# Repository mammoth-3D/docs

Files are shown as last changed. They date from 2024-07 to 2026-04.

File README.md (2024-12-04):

# mammoth-3D Documentation

The **Mammoth-3D Documentation** serves as an essential resource for several key reasons:

### 1. **Comprehensive Learning Resource**
The documentation offers a thorough overview of all the features and functionalities of the Mammoth-3D platform. Whether you're a beginner learning the basics or an advanced user exploring complex capabilities, the documentation provides step-by-step guides, tutorials, and detailed explanations. It helps users understand the various tools and how to apply them effectively in their projects.

### 2. **Efficient Problem-Solving**
Encountering issues or needing clarification on specific functionalities is common when using any complex software. The Mammoth-3D documentation acts as a troubleshooting guide, offering solutions to common problems and detailed instructions on how to navigate challenges. This can save users time and reduce frustration by providing quick answers and alternative approaches.

### 3. **Enhanced Workflow Integration**
For professionals using multiple software applications, understanding how Mammoth-3D integrates with other tools is crucial. The documentation covers compatibility, import/export processes, and best practices for maintaining data integrity across platforms. This information helps users create a seamless workflow, ensuring that their work in Mammoth-3D can be efficiently incorporated into broader projects.

### 4. **Access to Advanced Features**
Mammoth-3D offers a wide range of advanced features, including scripting and real-time collaboration. The documentation details how to access and utilize these features, enabling users to fully exploit the platform's potential. For instance, developers can learn how to write scripts to automate tasks, while teams can discover how to collaborate effectively on shared projects.

### 5. **Up-to-Date Information**
As Mammoth-3D continues to evolve, the documentation is regularly updated to reflect the latest features, updates, and best practices. This ensures that users have access to the most current information, helping them stay up-to-date with the latest developments and improvements in the software.

### 6. **Community and Support**
The documentation often includes links to community forums, support channels, and additional learning resources. This connectivity provides users with opportunities to ask questions, share experiences, and learn from other community members. It's an invaluable aspect of the documentation that extends learning beyond the written material.

In summary, the Mammoth-3D Documentation is an invaluable tool for maximizing the efficiency, effectiveness, and creativity of users on the platform. It provides essential information and support, making it an indispensable resource for anyone looking to master Mammoth-3D.

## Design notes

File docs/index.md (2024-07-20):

# **mammoth-3D Documentation**

mammoth-3D mods for 3D printers represent a significant leap forward in enhancing the capabilities of your 3D printing setup. Here's why they stand out in terms of design, functionality, performance, and user-friendliness, and how easily they integrate with popular printers like Voron, VZBOT, RatRig vCore, and many more:

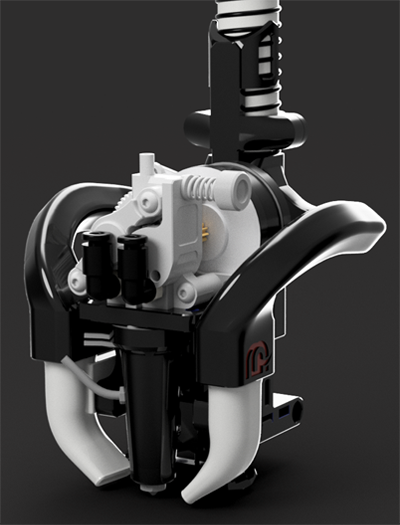
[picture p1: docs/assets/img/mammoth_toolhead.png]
mammoth-3D Toolhead


**Innovative Design**
mammoth-3D mods are meticulously crafted with a focus on both form and function:

- **Robust and Durable:** 
Built from high-quality materials, these mods are designed to last, ensuring your printer performs reliably over the long term.

- **Optimized Weight Distribution:** 
Careful design minimizes vibrations, leading to higher quality prints with fewer defects.

- **Aesthetic Appeal:** 
Sleek and modern designs not only enhance the functionality but also add a visually appealing touch to your printer.

**Unmatched Functionality**
Mammoth-3D mods are loaded with features that significantly improve the 3D printing experience:

- **Advanced Cooling Systems:** 
Ensures even temperature distribution, reducing the risk of warping and resulting in smoother, more precise prints.

- **Precision Mechanics:** 
High-precision components guarantee accurate movements, producing high-resolution prints with intricate details.

- **Customizable Settings:** 
Offers flexibility to adjust settings for specific printing needs, making it suitable for a wide range of projects.

**Superior Performance**
Experience the pinnacle of 3D printing performance with Mammoth-3D mods:

- **Enhanced Speed:** 
Optimized motion systems allow for faster printing speeds while maintaining high-quality output.

- **Consistency and Reliability:** 
Designed to deliver consistent performance over extended print runs, reducing material wastage and failed prints.

- **Energy Efficiency:** 
Engineered for power efficiency, these mods help lower operational costs and minimize environmental impact.

**User-Friendly Experience**
Mammoth-3D mods are designed with the user in mind, ensuring an easy and enjoyable printing experience:

- **Intuitive Interface:** 
Simple and user-friendly interfaces make setup and operation straightforward, even for beginners.

- **Comprehensive Documentation:**
Detailed guides and manuals help users quickly understand and implement the mods.

**Responsive Customer Support:** 
Dedicated support is available to assist with any questions or issues, ensuring a smooth user experience.

**Seamless Integration**
One of the standout features of Mammoth-3D mods is their compatibility with a wide range of 3D printers:

- **Modular Design:** These mods are designed to be modular, allowing for easy integration and upgrades across different printer models.

- **Plug-and-Play Installation:** Most mods can be installed with minimal adjustments, requiring only basic tools and technical knowledge.

- **Broad Compatibility:** Extensive testing ensures that Mammoth-3D mods work seamlessly with various firmware and hardware configurations, providing stability and optimal performance.

**Engaged Community and Ecosystem**
Join a vibrant community of 3D printing enthusiasts with Mammoth-3D:

- **Open Source and Customization:** Many mods are open source, encouraging users to customize and tweak them to fit specific needs.

- **Regular Updates:** Continuous improvements and updates based on community feedback keep the mods at the cutting edge of 3D printing technology.

**Conclusion:**

Mammoth-3D mods elevate your 3D printing experience through innovative design, superior functionality, exceptional performance, and user-friendly features. Their easy integration with a variety of 3D printer models, such as Voron, VZBOT, RatRig vCore, and more, makes them the ideal choice for anyone looking to enhance their 3D printing setup. Whether you are a hobbyist or a professional, Mammoth-3D mods provide the versatility and reliability needed to achieve outstanding printing results.

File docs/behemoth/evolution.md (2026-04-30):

# From mammoth to behemoth
## Engineering the Next Stage of High-Performance Gantries

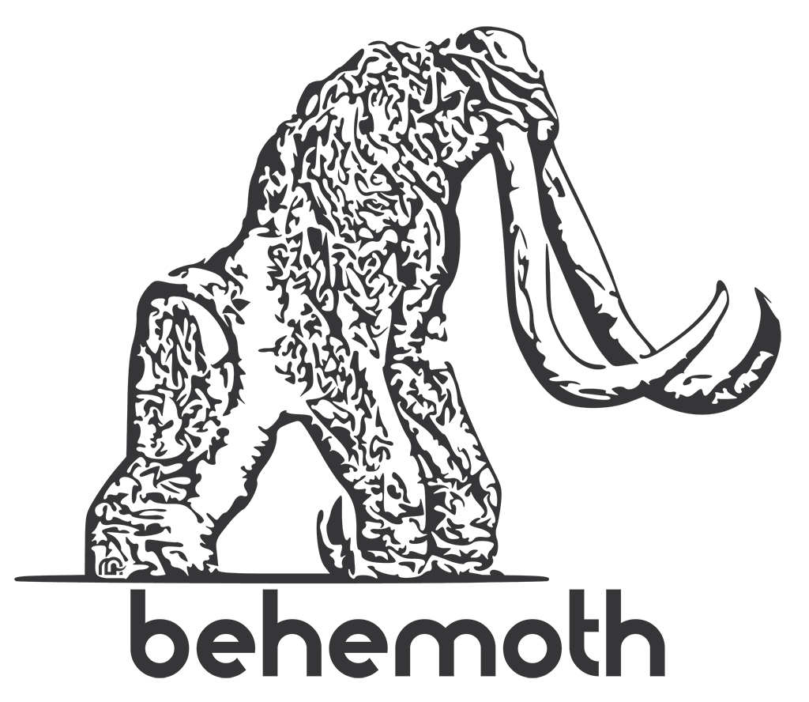
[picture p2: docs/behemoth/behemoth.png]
mammoth-3D Toolhead


In 2023, the open-source 3D printing landscape was largely defined by two platforms:

- Voron — known for precision engineering and strong community documentation  
- VZBot — known for aggressive speed and high-performance motion systems  

Each represented a different philosophy.

**mammoth** was created to unify them.

---

# Mammoth: Where Two Worlds Met

The mammoth-3D AWD Gantry was not an adapter or a light modification.

It was a complete ground-up redesign.

The goal was simple:

**Combine the structural precision of Voron with the speed-focused performance of VZBot — without compromise.**

## What mammoth Delivered

- True cross-compatibility between ecosystems  
- Support for high-speed configurations (30T pulleys)  
- Long shaft motor compatibility (5mm & 8mm)  
- Toolhead flexibility across platforms  

Rather than forcing one system into another, mammoth reimagined the gantry architecture itself.

It proved that performance and flexibility could coexist within a single engineered solution.

---

# Evolution Is Not a Version Number

behemoth is not “mammoth V2.”

It represents a structural shift in direction.

Where mammoth focused on merging ecosystems,  
behemoth focuses on establishing its own.

---

# behemoth: Designed for Independence

behemoth is engineered to move beyond adaptation.

It is the foundation of a standalone 3D printer platform — built with scalability, strength, and long-term evolution in mind.

---

## Built for Scale From the Start

- Initial platform size: **400 × 400mm**
- Long-term development target: **1000 × 1000mm multi-toolhead capability**

behemoth is not constrained by traditional desktop dimensions.

It is engineered to support large-format, high-rigidity builds from day one.

---

## Transitional Compatibility

In its current stage, behemoth supports Voron printers.

As development progresses, the platform transitions toward **3030 aluminum profile architecture**, creating a stronger and more independent structural standard.

This ensures long-term scalability and mechanical stability.

---

## Configurable Belt Architecture

behemoth supports multiple belt widths:

- 6 mm  
- 9 mm  
- 10 mm  
- 12 mm  

This allows builders to balance speed, torque capacity, and structural rigidity according to their performance goals.

---

## The mammoth Idler Pack — Refined Engineering

After a year of iterative testing and refinement, the idler system has been significantly improved:

- Direct access to idlers and bearings  
- No motor mount removal required  
- Belt tensioning through the idler pack  
- Reduced stress on motor shafts  

This design increases serviceability while improving long-term mechanical reliability.

---

## Builder-Focused Flexibility

behemoth supports:

- Double-shear configurations  
- Traditional idler setups  
- Modular customization options  

The platform is engineered to provide flexibility without sacrificing structural integrity.

---

# The Strategic Shift

mammoth demonstrated that ecosystems could be unified.

behemoth establishes a platform that can stand independently.

It reflects a move from integration  
to long-term architectural ownership.

---

# The Next Phase

behemoth is not the final form.

It is the beginning of a larger platform vision.

Further features and refinements will be introduced in the coming weeks as development continues.

If you would like to follow the progression or contribute feedback,  
join the discussion in [**#behemoth-general**](https://discord.com/channels/1240273232247132233/1470169338995675187)

**Engineering evolves. So do we.**

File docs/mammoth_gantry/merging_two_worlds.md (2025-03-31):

# **mammoth-3D AWD Gantry: Merging Two Worlds**

## **Origins of the mammoth-3D AWD Gantry**  

The idea for the **mammoth-3D AWD gantry** began in **April 2023**. At the time, **Voron 3D printers** were leading the open-source printer community, while **VZBot 3D printers** were pushing the boundaries of high-speed printing with impressive quality. 
This sparked a race, who would be the first to adapt and run a **VZBot toolhead** on a **Voron printer**?  

In **June 2023**, the **mammoth-3D Toolhead** was developed, allowing users to equip their **Voron printers** with the **Goliath hotend** and **CPAP cooling** for improved performance.  

By the end of **2024**, the **mammoth-3D AWD Gantry v6** was finalized—the first version made publicly available, documented as **version 1.7.3**.  

---

## **What Makes the mammoth-3D AWD Gantry Unique?**

Unlike modifications that adapt a **Voron gantry** to fit a **VZBot toolhead**, we **designed an entirely new gantry** from the ground up.  

### **Key Features**  

- **Cross-Compatible** – Use either **Voron toolheads** or the **VZBot toolhead** on the new gantry.  
- **Expanded Printer Support** – Now, **Voron toolheads** can also be mounted on a **VZBot printer**.  
- **High-Speed Optimization** – Supports **30T pulleys** and **long shaft motors (5mm or 8mm)**, allowing for maximum speed and flexibility in component selection.  

By doing this, we’ve effectively **brought two worlds together**, offering the best of both **Voron** and **VZBot** ecosystems.  

---

## ⚠️ **Important Considerations Before Installing**  

Before you decide to build a **mammoth-3D AWD gantry**, please be aware of the following:  

### 🔹 **No Official Voron Manual**  
While we provide **documentation** and a **Discord group**, our guide is not as detailed as the **Voron** manual. You should already be **comfortable assembling a stock 3D printer** before attempting this build.  

### 🔹 **Most Existing Parts Won’t Fit**  
Your current **gantry parts** will likely be **incompatible** with the new design, meaning you’ll need to **invest in new components**.  

### 🔹 **Frame Modifications Required**  
The **aluminum profiles** have changed and will need to be **cut to fit** your new gantry. Detailed information is available in the **[source guide](https://docs.mammoth-3d.ch/voron_3d_printers/awd_gantry_vz_toolhead_printed_version/bom/awdvz_sourcing_guide/)**.  

---

## **Welcome to the mammoth-3D Family!**  

If you’ve read through all of this and still want to take on the challenge, **welcome to the mammoth-3D family**. Where we push the limits of **high-speed, high-quality** 3D printing. 🚀

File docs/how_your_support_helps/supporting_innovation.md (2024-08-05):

## **Supporting Innovation with mammoth-3D. Find us on [Printables.com](https://www.printables.com/@Mammoth3D_2076590/models)**

By choosing to pay a small fee ($5 - $10) for Mammoth-3D parts, end users contribute to the continuous development and innovation of Mammoth-3D’s 3D printing technology. This support enables Mammoth-3D to:

- **Develop New Parts and Enhancements**: Ongoing revenue helps fund research and development, leading to improved and more efficient 3D printing components.
- **Improve Quality and Performance**: Continuous improvement efforts ensure that Mammoth-3D parts meet the highest standards of quality and performance.
- **Expand Material Options**: Funding supports the exploration and introduction of new materials, providing users with more choices for their projects.

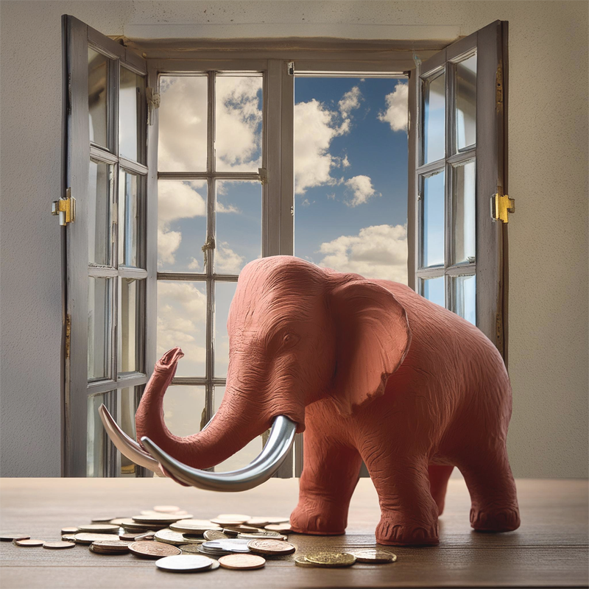
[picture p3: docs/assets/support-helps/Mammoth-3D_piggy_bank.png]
Mammoth-3D on www.printables.com


Mammoth-3D on www.printables.com mammoth-3D Piggy Bank (https://www.printables.com/@Mammoth3D_2076590/models)

**Open Source:**

Additionally, Mammoth-3D ensures that its contributions to the 3D printing community extend beyond immediate financial support. All published files and projects will move to open source after a period of six months. This means that if an end user does not wish to pay for the project files now, they will have access to these resources for free after six months. This approach balances immediate funding needs with a long-term commitment to open access and community support.

**The Cost of Development and Engineering Work for 3D Printed Components**

3D printing, also known as additive manufacturing, has revolutionized the manufacturing industry by offering unprecedented flexibility, customization, and efficiency. However, developing a 3D printed component or part involves various stages and costs. This blog will delve into the cost factors associated with the development and engineering work required to create a 3D printed part.

**1. Initial Design and Conceptualization**

The first stage in developing a 3D printed component is the design and conceptualization phase. This involves translating an idea into a viable digital model using Computer-Aided Design (CAD) software. The costs here are influenced by:

**Design Software**

- **CAD Software Licenses**: Professional CAD software can range from $100 to $1,000 per year per license. For complex projects, advanced software like SolidWorks, AutoCAD, or Rhino might be required.
- **Specialized Plugins and Tools**: Depending on the project's complexity, additional plugins or tools may be needed, further increasing the software costs.

**Designer and Engineer Fees**

- **Hourly Rates**: The hourly rate for a skilled designer or engineer can vary widely, from $50 to $150 or more, depending on their expertise and location.
- **Project Complexity**: More complex designs require more time and expertise, driving up costs.

**2. Prototyping and Testing**

Once the initial design is ready, prototyping and testing come into play. This phase ensures the design is functional and meets the required specifications.

**3D Printing Costs**

- **Material Costs**: The type of material used for 3D printing significantly impacts the cost. Common materials like PLA or ABS are cheaper, while specialized materials like metal or resin can be much more expensive. Prices range from $20 per kilogram for basic plastics to over $500 per kilogram for high-performance materials.
- **Printer Costs**: The cost of using a 3D printer depends on whether you own the printer or need to use a service. Owning a professional-grade 3D printer can cost anywhere from $5,000 to $100,000 or more. Alternatively, outsourcing to a 3D printing service can cost anywhere from $10 to $100 per printed part, depending on the size and complexity.

**Iterations and Refinements**

- **Multiple Prototypes**: Developing a final product often requires multiple iterations. Each prototype involves additional printing costs and time, with each iteration potentially costing between $50 and $500 or more, depending on the complexity and material used.
- **Testing and Analysis**: Testing the prototypes for functionality, durability, and compliance with specifications can involve additional costs, including specialized equipment and labor.

**3. Final Production Preparation**

Once the design is finalized, preparing for production involves several additional steps and costs.

**Final Design Adjustments**

- **Optimization for Manufacturing**: Adjusting the design to optimize it for mass production, such as reducing material usage or simplifying assembly, can require additional design work and cost.
- **Detailed Documentation**: Creating detailed manufacturing instructions, assembly guides, and quality assurance documents is essential for smooth production.

**Quality Assurance and Certification**

- **QA Processes**: Implementing quality assurance processes to ensure each part meets the required standards can add to the cost. This may involve additional testing, inspection, and documentation.
- **Certification Costs**: Depending on the industry, certification (e.g., ISO, CE) might be required, which involves additional costs for compliance testing and documentation.

**4. Post-Production Considerations**

Post-production costs can also impact the overall budget for developing a 3D printed part.

**Post-Processing**

- **Finishing and Assembly**: Post-processing steps like sanding, painting, or assembling multiple parts can add to the cost. These processes can be labor-intensive and may require specialized equipment.
- **Surface Treatment**: Additional treatments, such as heat treatment for metal parts or UV curing for resin parts, can further increase costs.

**Distribution and Logistics**

- **Packaging**: Proper packaging to protect the parts during transportation is necessary and can add to the cost.
- **Shipping**: Depending on the size and weight of the parts, shipping costs can vary significantly, especially for international shipments.

**Conclusion**

The cost of developing and engineering a 3D printed component or part is influenced by various factors, including design and conceptualization, prototyping and testing, final production preparation, and post-production considerations. While 3D printing offers significant advantages in terms of flexibility and customization, careful consideration of the associated costs is crucial for a successful and economically viable project. Additionally, by paying a small fee for Mammoth-3D parts, users not only receive high-quality components but also support the ongoing innovation and development efforts of Mammoth-3D, ensuring continuous improvements and advancements in 3D printing technology. Plus, the promise of open-source access after six months makes it an inclusive initiative that benefits the entire 3D printing community.

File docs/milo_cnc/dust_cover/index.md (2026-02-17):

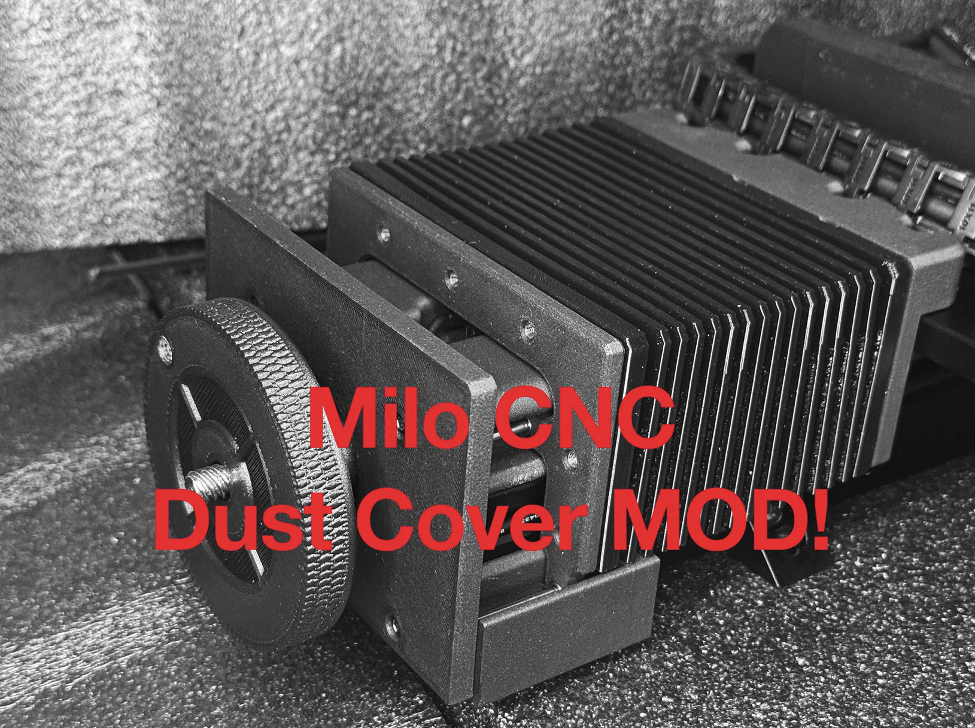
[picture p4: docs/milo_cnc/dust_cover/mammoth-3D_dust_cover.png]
mammoth-3D Milo CNC Dust Cover
# **The Milo CNC Dust Cover by mammoth-3D** 

**Why This Mod Helps.**

- By shielding your rails and lead screw, this dust cover reduces contamination, lowers maintenance, and keeps your machine running smoother for longer. Perfect for woodworking, plastics, aluminum, and general CNC use.

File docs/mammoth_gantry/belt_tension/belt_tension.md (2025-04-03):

# **Belt Tension Calculator**

## ⚠️ **Important: Check Before Tensioning!**  

Before you start tensioning your belts, **ensure the tensioner is not pulling on the motor shaft!**  

### 🛠️ **Examples of setups where this applies:**
- All AWD upgrades for Voron printers with the default belt configuration  
- Monolight gantry  
- VZBot 235 and 330  

### 🚨 **Avoid Motor Shaft Damage!**  
Applying too much tension at once **can cause the motor shaft to bend or even result in permanent damage**.  

### 🚨 **Double Shear Bearing** 

If your gantry uses **double shear** bearings to support the motor shaft, you don’t need to worry about bending the shaft. However, if you're tensioning the belts via the motor shaft, be cautious not to **overstretch the belt**.

### ✅ **Recommended Tensioning Steps:**  
1. Start with an initial tension of **110-120 Hz**.  
2. **Increase in steps of 10–15 Hz at a time**.  
3. Move the gantry and belts to distribute tension.  
4. Repeat the process **only if needed** to reach the desired tension.    

Following this method ensures **a safer and more precise tensioning process**.  

## **Registration Drives**
Registration drives are crucial for accurate positioning, especially in applications like 3D printers. Higher belt tensions can improve belt tensile modulus and increase meshing interference, both of which help reduce backlash. The optimal tension values for these applications should be determined experimentally to ensure the desired performance characteristics are met.

As a starting point, a registration factor between **1.5** and **2.0** is recommended. However, it’s important to note that many 3D printers may not be able to handle a registration drive factor over **1.0**. You can find more infos in the **[Gates PDF](https://www.gates.com/content/dam/gates/home/knowledge-center/resource-library/catalogs/light-power-and-precision-manual.pdf)**.

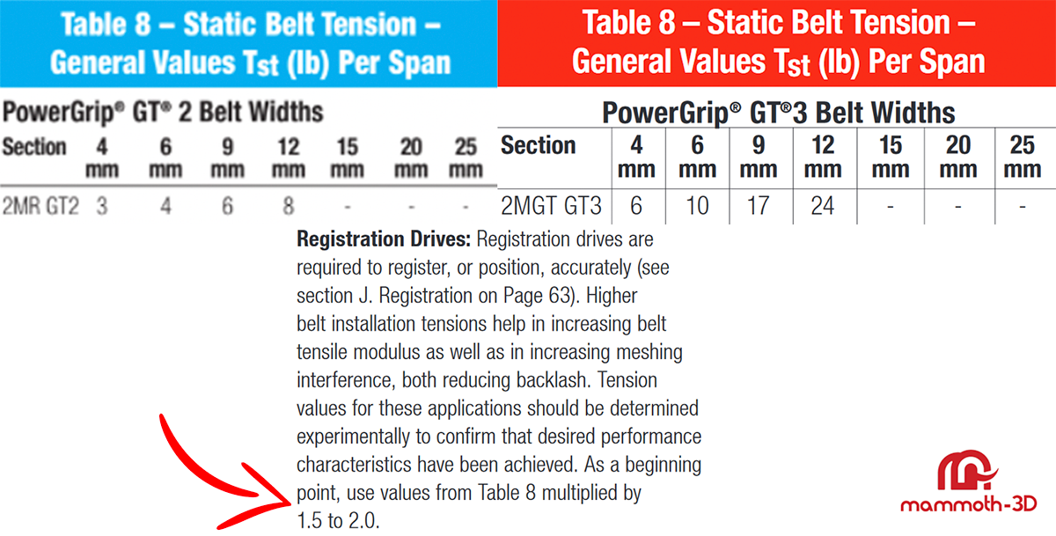
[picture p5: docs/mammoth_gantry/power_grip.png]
Power Grip

### **For example:** 
**Voron [(Belt Tension)](https://docs.vorondesign.com/tuning/secondary_printer_tuning.html#belt-tension)** printers specify a registration factor of **0.5** on GT2 6mm belts (equivalent to **2lb** of tension) and **VZbot [(Belt Tension)](https://docs.vzbot.org/general/belt-tensioning/#vzbot-330)** printers specify a registration factor of **0.8375** up to **1.5** on GT2 6mm belts (equivalent to **3.35lb** up to **6lb** of tension)

## **Calculator**
Use this calculator to determine the optimal belt tension frequency, or refer to the table below for quick belt information.

<style>
    :root {
        --md-primary-fg-color:        #9E1414;  /* Primary Red */
        --md-accent-fg-color:         #EC6565;  /* Accent Red */
        --md-primary-fg-color--light: #AD4343;  /* Light Red */
        --md-primary-fg-color--dark:  #9E1414;  /* Dark Red */
    }

    .calculator-table {
        width: 100%;
        max-width: 600px;
        margin: auto;
        border-collapse: collapse;
    }

    .calculator-table th, .calculator-table td {
        border: 1px solid var(--md-primary-fg-color--light);
        padding: 10px;
        text-align: left;
    }

    .calculator-table th {
        background-color: var(--md-primary-fg-color--light);
        color: white;
    }

    select, input {
        width: 100%;
        padding: 8px;
        font-size: 16px;
        border: 1px solid var(--md-primary-fg-color--light);
    }

    button {
        width: 100%;
        padding: 10px;
        background-color: var(--md-primary-fg-color); /* Primary Red */
        color: white;
        font-size: 18px;
        border: none;
        cursor: pointer;
    }

    button:hover {
        background-color: var(--md-primary-fg-color--dark); /* Dark Red */
    }

    #result {
        font-size: 18px;
        font-weight: bold;
        text-align: center;
        margin-top: 15px;
        color: var(--md-primary-fg-color);
    }

    .shadow {
        height: auto;
        width: auto;
        box-shadow: 0 0 5px 5px white;
    }

    .mermaid {
        display: flex !important;
        justify-content: center;
    }

    .shadow-dark {
        height: auto;
        width: auto;
        box-shadow: 0 0 5px 5px #1e1e1e;
    }

    .md-typeset__table {
        min-width: 100%;
    }

    .md-typeset table:not([class]) {
        display: table;
    }
</style>

<table class="calculator-table">
    <tr>
        <th>Select Belt Type:</th>
        <td>
            <select id="beltType">
                <option value="GT2">GT2</option>
                <option value="GT3">GT3</option>
            </select>
        </td>
    </tr>
    <tr>
        <th>Select Belt Width (mm):</th>
        <td>
            <select id="beltWidth">
                <option value="6">6 mm</option>
                <option value="9">9 mm</option>
                <option value="10">10 mm</option>
                <option value="12">12 mm</option>
            </select>
        </td>
    </tr>
    <tr>
        <th>Select Factor:</th>
        <td>
            <select id="factor">
                <option value="1">1</option>
                <option value="1.25">1.25</option>
                <option value="1.5">1.5</option>
                <option value="1.75" selected>1.75 (Default)</option>
                <option value="2">2</option>
            </select>
        </td>
    </tr>
    <tr>
        <th>Enter Belt Length (mm):</th>
        <td>
            <input type="number" id="beltLength" value="150">
        </td>
    </tr>
    <tr>
        <td colspan="2">
            <button id="calculate">Calculate</button>
        </td>
    </tr>
</table>

## **mammoth-3D Gantry Belt Tension** 

All mammoth-3D gantries are designed with the same principle: **Do not pull on the motor shaft when tensioning the belts**.  

Whether it's a Voron or VZBot gantry, they all function the same way. Over-tensioning can still damage short motor shafts, even if they are not directly used for belt tensioning.  

Refer to the table below for the recommended belt tension values for mammoth-3D gantries.

### **Belt Tension / Short Shaft Motor**  

| **mammoth-3D Gantry** | **GT2 Belts Minimum Tension** | **GT2 Belts Maximum Tension** | **GT3 Belts Minimum Tension** | **GT3 Belts Maximum Tension** |  
|:---|:---:|:---:|:---:|:---:|
| **3D Printed** | 6mm Belts 147.40Hz / 4lbf | 6mm Belts 180.53Hz / 6lbf | ❌ Not Recommended | ❌ Not Recommended |  
| **Aluminum** | 6mm Belts 147.40Hz / 4lbf | 6mm Belts 180.53Hz / 6lbf | ❌ Not Recommended | ❌ Not Recommended |  

### **Belt Tension / Long Shaft Motor (Double Shear)**  

| **mammoth-3D Gantry** | **GT2 Belts Minimum Tension** | **GT2 Belts Maximum Tension** | **GT3 Belts Minimum Tension** | **GT3 Belts Maximum Tension** |  
|:---|:---:|:---:|:---:|:---:|
| **3D Printed** | 6mm Belts 180.53Hz / 6lbf | 6mm Belts 194.99Hz / 7lbf | ❌ Not Recommended | ❌ Not Recommended |  
| **Aluminum** | 6mm Belts 180.53Hz / 6lbf | 6mm Belts 194.99Hz / 7lbf | 6mm Belts 258.45.53Hz / 15lbf| 6mm Belts 279.16Hz / 17.5lbf |

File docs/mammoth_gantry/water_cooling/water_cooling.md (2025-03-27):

# **Water Cooling**

!!! tip
    **The water cooling inlet should always (or if possible) be the lowest point and the outlet should always be the highest point in your water cooling setup.**

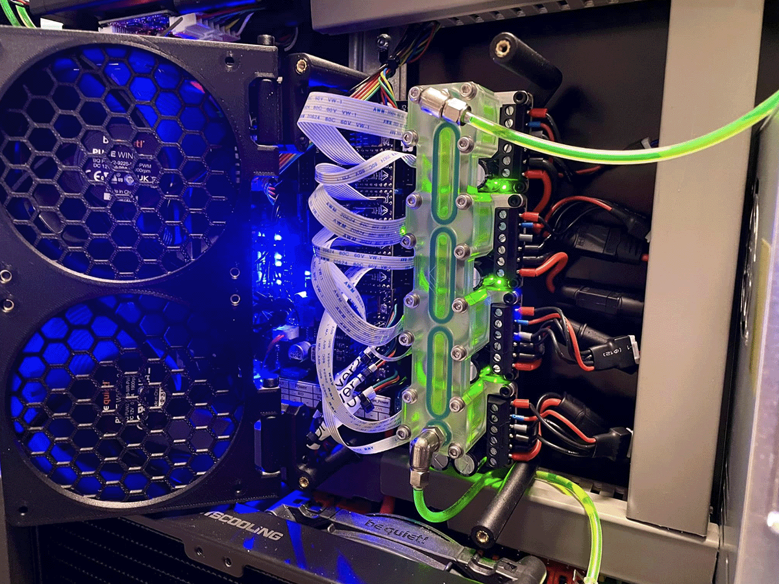
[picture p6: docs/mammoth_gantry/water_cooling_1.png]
Water Cooling setup


!!! note "Pipe Length"
    The pipe length between the hotend and Y1 motor, as well as between the X and Y motors and the X1 motor and pump, is very long. It is recommended to use quick connectors for the day you need to remove the gantry without having to remove all the pipes as well.

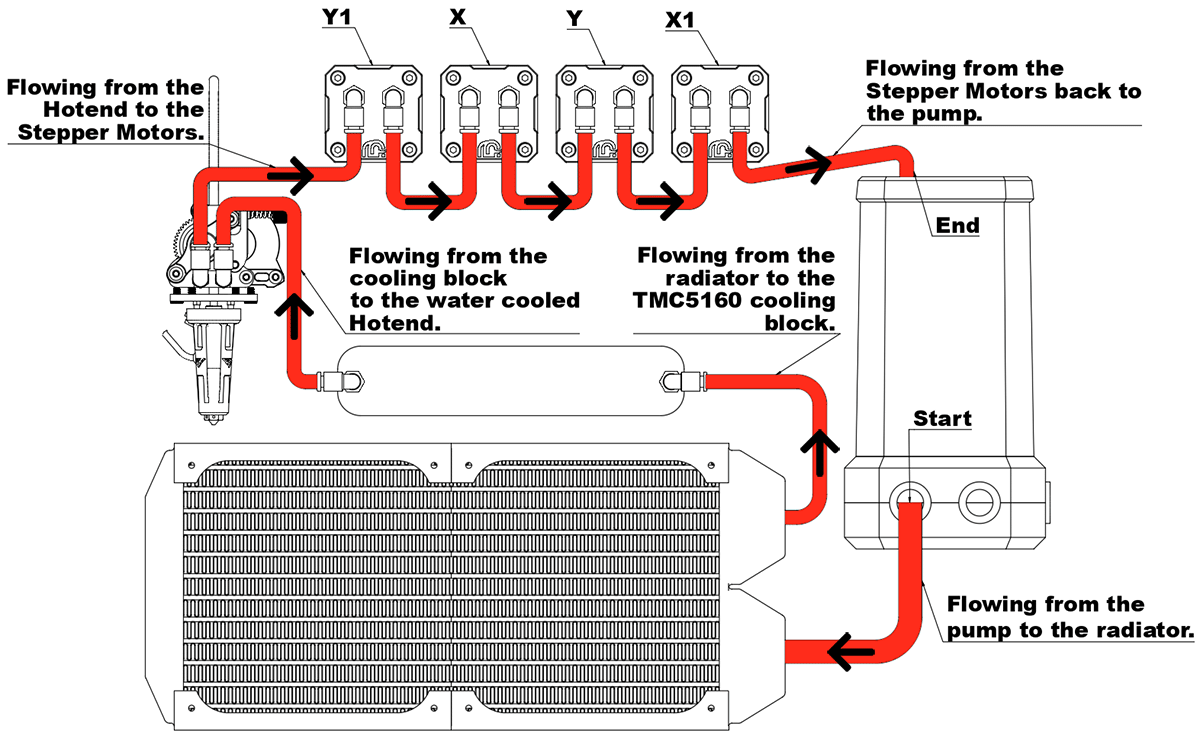
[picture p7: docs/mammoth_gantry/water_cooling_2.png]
Pipes


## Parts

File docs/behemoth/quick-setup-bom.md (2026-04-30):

<!DOCTYPE html>
<html>
<head>
  <title>behemoth BOM Generator</title>
</head>
<body>

<h2>BOM Configuration</h2>

<label><strong>3D Printer</strong></label><br>
<select id="printer">
  <option value="">-- Select Printer --</option>
  <option>behemoth</option>
  <option>Voron 2.4</option>
  <option>Voron Trident</option>
</select><br><br>

<label><strong>Printer Size</strong></label><br>
<select id="size">
  <option value="">-- Select Size --</option>
  <option>300</option>
  <option>350</option>
  <option>400</option>
</select><br><br>

<label><strong>Hotend</strong></label><br>
<select id="hotend">
  <option value="">-- Select Hotend --</option>
  <option>Hell Fire</option>
  <option>Goliath Air</option>
  <option>Goliath Water</option>
  <option>Rapido</option>
  <option>Tricorn</option>
</select><br><br>

<label><strong>X Axis</strong></label><br>
<select id="axis"></select><br><br>

<label><strong>XY Belts</strong></label><br>
<select id="belt">
  <option value="">-- Select Belt --</option>
  <option>9mm</option>
  <option>12mm</option>
</select><br><br>

<label><strong>Motor Shaft Diameter</strong></label><br>
<select id="diameter">
  <option value="">-- Select Diameter --</option>
  <option>5mm</option>
  <option>8mm</option>
</select><br><br>

<label><strong>Motor Shaft Length</strong></label><br>
<select id="length">
  <option value="">-- Select Length --</option>
  <option>20mm to 25mm</option>
  <option>30mm to 40mm</option>
  <option>55mm to 60mm</option>
</select>

<br><br>

<button onclick="downloadCSV()">Download CSV</button>

<hr>

<table border="1" width="100%">
<thead>
<tr>
  <th>Qty</th>
  <th>Part Number</th>
  <th>Description</th>
  <th>Link</th>
</tr>
</thead>
<tbody id="bomTable">
<tr><td colspan="4">Make selections</td></tr>
</tbody>
</table>

<script>

// ---------------- DATA ----------------
let bom = {};

// ---------------- PART NUMBER ----------------
function makePartNumber(name){
  return "BH-" + name
    .toLowerCase()
    .replace(/behemoth/g, "")
    .replace(/voron/g, "")
    .replace(/v24/g, "")
    .replace(/vt/g, "")
    .replace(/[^a-z0-9]+/g, "-")
    .replace(/-+/g, "-")
    .replace(/^-|-$/g, "")
    .toUpperCase()
    .substring(0, 40);
}

// ---------------- LINK ----------------
function makeLink(partNumber){
  return `https://behemoth.local/${partNumber}`;
}

// ---------------- ADD ITEM ----------------
function addItem(qty, name){

  const key = makePartNumber(name);

  if(!bom[key]){
    bom[key] = {
      qty: 0,
      part: key,
      desc: name,
      link: makeLink(key)
    };
  }

  bom[key].qty += qty;
}

// ---------------- AXIS RULE (UPDATED) ----------------
function updateAxis(){

  const size = sizeEl.value;
  axisEl.innerHTML = `<option value="">-- Select Axis --</option>`;

  if(!size) return;

  if(size === "300"){
    axisEl.innerHTML += `<option>High Speed 300</option>`;
    axisEl.innerHTML += `<option>High Temp 300</option>`;
  }

  if(size === "350"){
    axisEl.innerHTML += `<option>High Speed 350</option>`;
    axisEl.innerHTML += `<option>High Temp 350</option>`;
  }

  if(size === "400"){
    // 🚨 ONLY HIGH TEMP ALLOWED
    axisEl.innerHTML += `<option>High Temp 400</option>`;
  }
}

// ---------------- MAIN ----------------
function generateBOM(){

  bom = {};

  const printer = printerEl.value;
  const size = sizeEl.value;
  const hotend = hotendEl.value;
  const axis = axisEl.value;
  const belt = beltEl.value;
  const diameter = diameterEl.value;
  const length = lengthEl.value;

  if(!printer || !size || !hotend || !axis || !belt || !diameter || !length){
    table.innerHTML = "<tr><td colspan='4'>⚠️ Complete selections</td></tr>";
    return;
  }

  // ---------------- SAFETY CHECK ----------------
  if(size === "400" && axis.includes("High Speed")){
    table.innerHTML = "<tr><td colspan='4'>❌ Invalid: 400 only supports High Temp axis</td></tr>";
    return;
  }

  // ---------------- BASE ----------------
  const baseSets = [
    "Set1 X1 Y1 Motor Mount",
    "Set2 X Y Motor Mount",
    "Set3 X1 Y1 Idler Pack",
    "Set4 Tension Arms",
    "Set5 X Y Idler Pack",
    "Set6 XY Joiners",
    "Set22 Toolhead"
  ];

  baseSets.forEach(s => addItem(1, s));

  if(printer === "behemoth" || printer === "Voron 2.4"){
    addItem(1, "Set12 V24 Fixed Z Joints");
  }

  if(printer === "Voron Trident"){
    addItem(1, "Set13 VT Fixed Z Joints");
  }

  // ---------------- HOTEND ----------------
  if(hotend === "Hell Fire"){
    addItem(1, "Set25 Hell Fire Plate");
    addItem(1, "Set28 Hell Fire 150W");
  } else {
    addItem(1, "Set26 Universal Hotend Plate");
  }

  // ---------------- AXIS ----------------
  addItem(1, axis + " X-Axis");

  // ---------------- BELT ----------------
  if(belt === "9mm"){
    addItem(6, "Set14 9mm Idler Teeth");
    addItem(8, "Set15 9mm Idler Smooth");
    addItem(1, "Set23 9mm Clamp");
  } else {
    addItem(6, "Set16 12mm Idler Teeth");
    addItem(8, "Set17 12mm Idler Smooth");
    addItem(1, "Set24 12mm Clamp");
  }

  // ---------------- BEARINGS ----------------
  if(diameter === "8mm"){
    addItem(8, "8mm Bearings");
  }

  // ---------------- SHAFT RULE ----------------
  const longShaft = (length === "55mm to 60mm");

  if(!longShaft){

    if(diameter === "5mm"){
      addItem(4, "5mm Shaft Couplers");
      addItem(4, "M5 70mm Dowel Pins");
    }

    if(diameter === "8mm"){
      addItem(4, "8mm Shaft Couplers");
      addItem(4, "M8 70mm Dowel Pins");
    }
  }

  render();
}

// ---------------- RENDER ----------------
function render(){

  let html = "";

  Object.keys(bom).forEach(k => {

    const i = bom[k];

    html += `
      <tr>
        <td>${i.qty}</td>
        <td>${i.part}</td>
        <td>${i.desc}</td>
        <td><a href="${i.link}" target="_blank">Open</a></td>
      </tr>`;
  });

  table.innerHTML = html;
}

// ---------------- CSV ----------------
function downloadCSV(){

  generateBOM();

  let rows = [["Qty","Part Number","Description","Link"]];

  Object.keys(bom).forEach(k => {
    const i = bom[k];
    rows.push([i.qty, i.part, i.desc, i.link]);
  });

  const csv = rows.map(r =>
    r.map(v => `"${v}"`).join(",")
  ).join("\n");

  const blob = new Blob([csv], {type:"text/csv"});
  const a = document.createElement("a");

  a.href = URL.createObjectURL(blob);
  a.download = "behemoth BOM.csv";
  a.click();
}

// ---------------- ELEMENTS ----------------
const printerEl = document.getElementById("printer");
const sizeEl = document.getElementById("size");
const hotendEl = document.getElementById("hotend");
const axisEl = document.getElementById("axis");
const beltEl = document.getElementById("belt");
const diameterEl = document.getElementById("diameter");
const lengthEl = document.getElementById("length");
const table = document.getElementById("bomTable");

// events
sizeEl.addEventListener("change", updateAxis);
document.querySelectorAll("select").forEach(s =>
  s.addEventListener("change", generateBOM)
);

</script>

</body>
</html>

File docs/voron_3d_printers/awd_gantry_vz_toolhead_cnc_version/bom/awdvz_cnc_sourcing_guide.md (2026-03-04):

# **Sourcing Guide**

## **Hardware Kits**

!!! tip
    **Your X-axis needs to be modified or you need to buy new 2020 aluminium profile and shorter MGN9 rails**

    ### Voron 2.4 250mm
    - X: 314mm  
    - Back: 167mm  
    - Side: 350mm (unchanged)  
    - MGN9 X rail should be 20mm shorter → 280mm  

    ### Voron 2.4 300mm
    - X: 364mm  
    - Back: 217mm  
    - Side: 400mm (unchanged)  
    - MGN9 X rail should be 20mm shorter → 330mm  

    ### Voron 2.4 350mm
    - X: 414mm  
    - Back: 267mm  
    - Side: 450mm (unchanged)  
    - MGN9 X rail should be 20mm shorter → 380mm

### **BOM Kit Version 1.7.3**

| **Quantity** | **Description** | **Link** | 
|:---|---|---:|
| 1x | mammoth-3D AWD Gantry Hardware Kit | [Mellow 3D](https://www.aliexpress.com/item/1005008885691336.html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)|
| 1x | mammoth-3D AWD Pulleys 20T 6mm belt Kit | [Mellow 3D](https://www.aliexpress.com/item/1005004374407134.html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)|

## **BOM Version 1.7.3**

### **AWD Gantry Hardware**

| **Quantity** | **Description** | |
|:---|---|---:|
|  6x | M2x8 Self-tapping Screw | |
|  30x | M3x6 BHCS | |
|  16x | M3x8 BHCS | |
|  4x | M3x10 BHCS | |
|  8x | M3x14 BHCS | |
|  2x | M3x16 BHCS | |
|  4x | M3x30 BHCS | |
|  8x | M3x6 SHCS | |
|  30x | M3x8 SHCS | |
|  2x | M3x10 SHCS | |
|  16x | M3x12 SHCS | |
|  2x | M3x25 SHCS | |
|  6x | M3x32 SHCS | |
|  12x | M3x8 FHCS | |
|  4x | M3x10 FHCS | |
|  4x | M3x4 Flat Head Ultra Low Profile | |
|  8x | M3x5 Flat Head Ultra Low Profile | |
|  6x | M3x6 Flat Head Ultra Low Profile | |
|  10x | M3x8 Flat Head Ultra Low Profile | |
|  2x | M3x10 Flat Head Ultra Low Profile | |
|  6x | M3xD5xL21.5 Mellow Sholder Bolts | |
|  8x | M3 3.1x6x20 Standoff Spacer  | |
|  18x | M3 Lock Nut | |
|  10x | M3 Square Nut 5,4x5,4mm | |
|  22x | M3 Drop-in T-nut | |
|  36x | M3 Threaded Insert (M3x5mmx4mm) | |
|  2x | M4x30 SHCS | |
|  4x | M4xD5xL25 Mellow Sholder Bolts | |
|  2x | M4xD5X30 Sholder Bolts | |
|  8x | M4 Lock Nut | |
|  6x | M4 4x9x1 Shim | |
|  8x | M5x10 BHCS | |
|  12x | M5x16 BHCS | |
|  18x | M5 5x7x1mm Shim | |
|  5x | M5 5x7x1.5mm Shim | |
|  6x | M5 5x6x10.5 Mellow Standoff Spacer  | |
|  4x | M5 5x6x11.5 Mellow Standoff Spacer  | |
|  24x | M5 Drop-in T-nut | |
|  4x | GT2 20T 6mmBelt - B5 | |
|  4x | F695 BEARING  | |

### **Pulleys**

!!! warning
    This MOD was made for the Mellow 3D Pulleys 8.5 / 6.5. (Same as in the VZBOT Kit) Please check before using different once.

| **Quantity** | **Description** | **Image** | **Link** |
|:---|---|---|---:|
|  10x | 20 Teeth (Mellow_GT2_20T_5x12x8.5_5020808027) | Mellow_GT2_20T_5x12x8.5_5020808027 | [Mellow 3D](https://www.aliexpress.com/item/1005004374407134.html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) |
|  6x | Without Teeth (Mellow_GT2_20T_5x12x8.5_5020808028) | Mellow_GT2_20T_5x12x8.5_5020808028 | [Mellow 3D](https://www.aliexpress.com/item/1005004374407134.html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) |

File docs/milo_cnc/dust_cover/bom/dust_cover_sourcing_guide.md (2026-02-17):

# **Sourcing Guide**

## **BOM Version 1.0**

### **Dust Cover Hardware**

| **Quantity** | **Description** | **Link** |
|:---|---|---:|
|  2x | 2.5mm CNC Kitchen Threaded Insert | [Threaded Insert](https://cnckitchen.store/products/gewindeeinsatz-threaded-insert-m2-5-standard-100-stk-pcs) |
|  2x | M2.5x8 SHCS | Reuse the two installed on the CNC |
|  1x | OMRON SS-5GL | Reuse the one installed on the CNC |
|  19x | M3 Threaded Insert (M3x5mmx4mm) | [Threaded Insert](https://www.3djake.ch/en-CH/ruthex/threaded-insert-m3-voron-100-pieces?sai=15775) |
|  14x | M3x6 Flat Head Ultra Low Profile | [Ultra Low](https://de.aliexpress.com/item/1005006209329445.html?) |
|  4x | M3x8 SHCS | |
|  4x | M3x20 SHCS | |
|  4x | M3 Washer | |
|  6x | M5x12 BHCS | Reuse the four installed on the CNC |
|  2x | M5 Drop-in T-nut | |
|  4x | Dowel Pin M3x50mm | [Dowel Pin](https://www.amazon.de/dp/B07NVF2DW1?ref=ppx_yo2ov_dt_b_fed_asin_title) |
|  12x | Sliding bearings (M3borex5x5mm) | [Sliding bearing](https://www.amazon.de/dp/B07JC8X45N?ref=ppx_yo2ov_dt_b_fed_asin_title) |
|  2x | Adjusting Ring 8mm Bore | Reuse the two installed on the CNC |
|  2x | F608 Bearing | Reuse the two installed on the CNC |
|  4x | 608-ZZ Bearing | Reuse the four installed on the CNC |
|  8x | Round Micro Magnets (6x3mm-N52) | [Magnet](https://de.aliexpress.com/item/1005009253310570.html?) |

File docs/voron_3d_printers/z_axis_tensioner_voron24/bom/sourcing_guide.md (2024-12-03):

# **Sourcing Guide**

## **Hardware Kits**

### **BOM Kit**

| **Quantity** | **Description** | **Link** | 
|:---|---|---:|
| 1x | mammoth-3d Tool-free Z-Axis Belt Tensioner hardware Kit (all 4) | [Mellow 3D](https://www.aliexpress.com/item/1005007628312911.html) |

## **BOM Version 1.3**

| **Quantity** | **Description** | **Standard** | **Link** |
|:---|---|---|---:|
| 16x | M3 Threaded Insert (M3x5mmx4mm) | | [ruthex](https://www.amazon.de/ruthex-Gewindeeinsatz-VORON-Gewindebuchsen-Kunststoffteile/dp/B0CDH36ZMX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ÅMÅŽÕÑ&crid=25CI6CSNHW9JK&dib=eyJ2IjoiMSJ9.PvhvKkww2ozhdvApJYbszb-tdtBXO2QnrSPIDUmJtfCNT0RgRaY2fJn5MP1fp61237Q5VSxyh8GwLxBQYYaRxBUcP4tjFVGX6kaVte4TIEWTozebED5hNXqBmWEWrjbS5lO_D_BhdW9TuWCJYzu8x94_cpk_p0RFxSV73lhp7QNhufwQgZMywhqHxoi4d32Bvkh-2Bs9DN6gj5ZYrZqMCt15AF753GDClDuCg4hyq14cxSjxuYKIHPCWe-DJ1LQ_pIGReCjfZqNB8vH5FUK0zeNU8jkhSoGlrkdaO-NHZdw.7hMPLVCOm3aOZLDktIX-UwkQOFTdJdoiDRDwzCKzv-w&dib_tag=se&keywords=M3+Threaded+Insert+voron&nsdOptOutParam=true&qid=1732441914&sprefix=m3+threaded+insert+voron%2Caps%2C64&sr=8-2-spons&sp_csd=d2lkZ2V0TmFtZT1zcF9hdGY&psc=1) |
| 16x | M3x25 SHCS | ISO 4762 / DIN 912 | [Bolt Depot](https://boltdepot.com/Product-Details?product=13640) |
| 4x | M4 Washer | ISO 4762 / DIN 912 | [Bolt Depot](https://boltdepot.com/Product-Details?product=4514) |
| 12x | M4 Lock Nut | ISO 4762 / DIN 912 | [Belt Depot](https://boltdepot.com/Product-Details?product=4793) |
| 4x | M4 Flat Head Screws 30mm | ISO 4762 / DIN 912 | [Belt Depot](https://boltdepot.com/Product-Details?product=13263) |  
| 24x | M5 5x7x1mm Shim | Aluminium / DIN 912| [XRAY](https://www.eurorc.com/product/33229/xray-alu-shim-5x7x10mm-10) |
| 8x | M5x10 BHCS | ISO 7380-1 | [Belt Depot](https://boltdepot.com/Product-Details?product=15646) |
| 4x | M5x30 BHCS | ISO 7380-1 | [Belt Depot](https://boltdepot.com/Product-Details?product=15651) |
| 12x | Drop-in T-nut, M5 | ISO 7380-1 | [ZFhong](https://de.aliexpress.com/item/32805163712.html?gatewayAdapt=glo2deu) |
| 4x | Sholder bolt 25mm: Shoulder Diameter (d) 5mm / Thread Size 4mm | ISO 4762 / DIN 912 | [Aliexpress](https://de.aliexpress.com/item/1005006421378844.html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) |
| 8x | Sholder bolt 30mm: Shoulder Diameter (d) 5mm / Thread Size 4mm | ISO 4762 / DIN 912 |[Aliexpress](https://de.aliexpress.com/item/1005006421378844.html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) |
| 4x | Mellow Pulleys 14/11 Smooth Wheel Bore 5mm GT2 | Aluminium |[Mellow 3D](https://de.aliexpress.com/item/33023133633.html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) |
| 8x | Mellow Pulleys 14/11 20 Tooth Wheel Bore 5mm GT2 | Aluminium |[Mellow 3D](https://de.aliexpress.com/item/33023133633.html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) |
| 4x | GATES-LL-2GT Belt (9mm wide) | |[Mellow 3D](https://www.aliexpress.com/item/32952396111.html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) |

### **Z-Axis 9mm Belt**

!!! warning
    For the Tool-free Z-Axis Belt Tensioner you will need new Z-Axis Belts.
    The stock belts are to **short** for this MOD.

!!! tip
| Voron 2.4 250x250 | Voron 2.4 300x300 | Voron 2.4 350x350 |
|:---|---|---:|
| You will need 4x 1000mm belt / Total 4 meters. | You will need 4x 1100mm belt / Total 4.4 meters. | You will need 4x 1200mm belt / Total 4.8 meters. |

### **Pulleys**

!!! warning
    This MOD was made for the Mellow 3D Pulleys 14/11. Please check before 
    using different once.

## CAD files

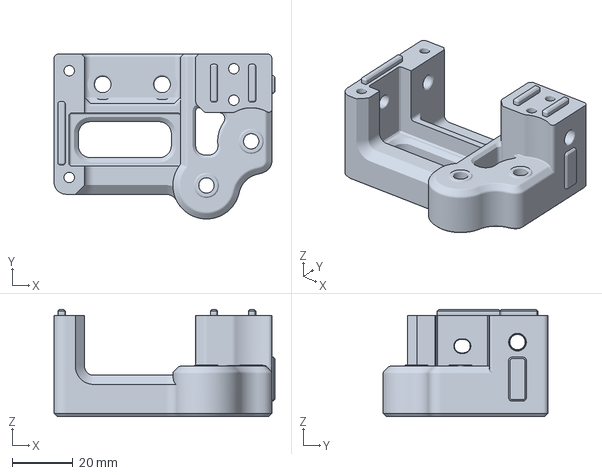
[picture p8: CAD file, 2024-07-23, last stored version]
docs/voron_3d_printers/z_axis_tensioner_voron24/belt_tensioner_mainbody_right_Ver.1.00 x2.3mf
72.5 x 54.1 x 35.1 mm

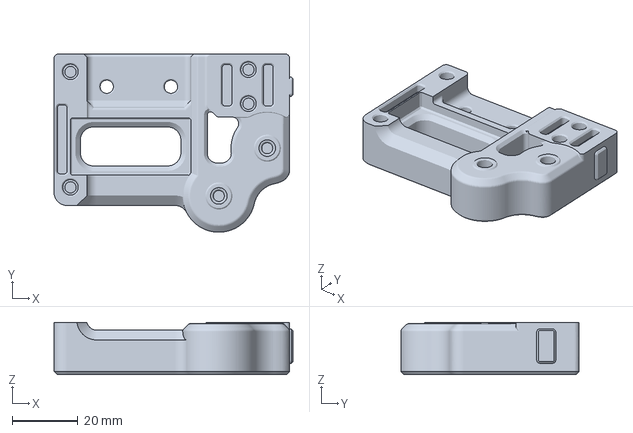
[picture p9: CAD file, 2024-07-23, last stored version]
docs/voron_3d_printers/z_axis_tensioner_voron24/belt_tensioner_coverbody_left_Ver.1.00 x2.3mf
72.5 x 54.1 x 15.9 mm

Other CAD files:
docs/voron_3d_printers/z_axis_tensioner_voron24/belt_tensioner_mainbody_left_Ver.1.00 x2.3mf
docs/voron_3d_printers/z_axis_tensioner_voron24/belt_tensioner_coverbody_right_Ver.1.00 x2.3mf

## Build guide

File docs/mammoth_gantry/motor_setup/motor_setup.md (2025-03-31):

# **Motor Setup**

## **The motor setup remains the same across all gantries.**
Regardless of whether you are using it on a Voron 3D Printer, VZBOT, or RatRig vCore 3.1 or 4.

## **AWD Configuration:**
- The X motor is always in the front left.
- The Y motor is always in the front right.
- The X1 motor is always in the back right.
- The Y1 motor is always in the back left.

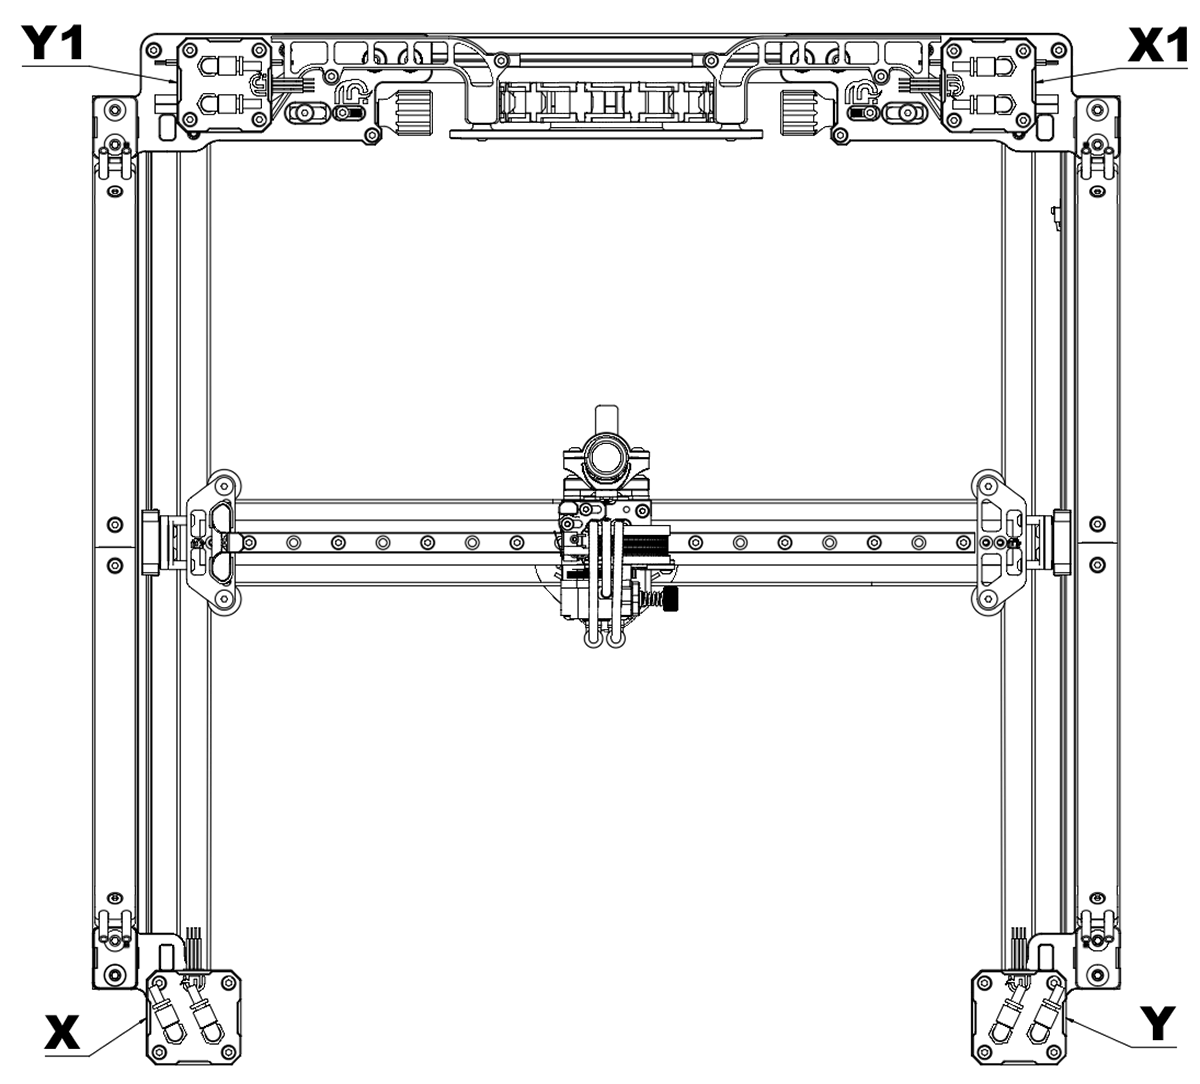
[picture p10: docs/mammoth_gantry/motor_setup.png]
mammoth-3D Gantry Motor Setup


## **2WD Configuration:**
- The X1 (X) motor is always in the back right.
- The Y1 (Y) motor is always in the back left.

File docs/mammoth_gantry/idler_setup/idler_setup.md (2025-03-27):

# **Idler Setup**

!!! note "Pulleys and Idlers"
    It is irrelevant whether you mount your motors on the mammoth-3D gantry at the top or bottom. The idlers and pulley positions will always remain the same, as seen in the images below.

    - VZ Toolhead / X-axis rail is top-mounted. For this setup, you will need VZ XY joiners.
    - Voron Toolhead / X-axis rail is front-mounted. For this setup, you will need mammoth-3D joiners.

| 20T Pulley / VZ Toolhead  |
|:-----------------------------------------------:|
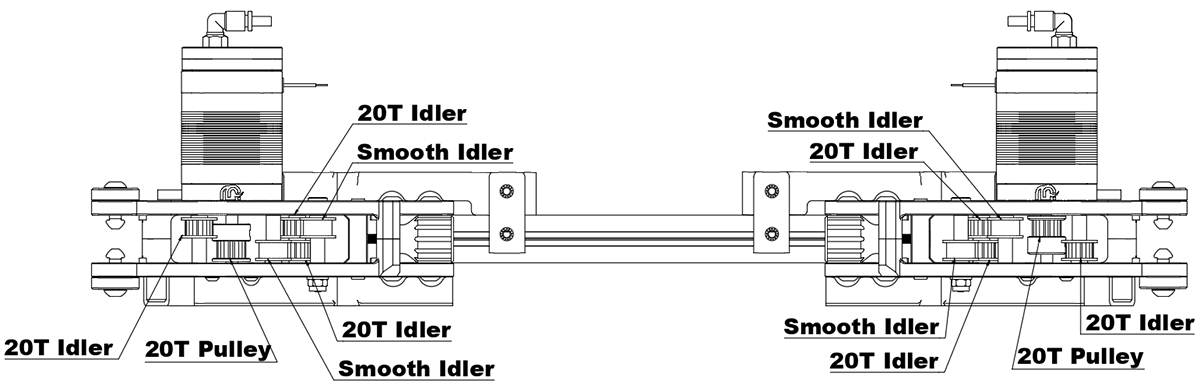
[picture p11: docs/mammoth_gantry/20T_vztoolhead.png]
mammoth-3D Gantry 20T Pulley and VZ Toolhead
||

| 30T Pulley / VZ Toolhead |
|:-----------------------------------------------:|
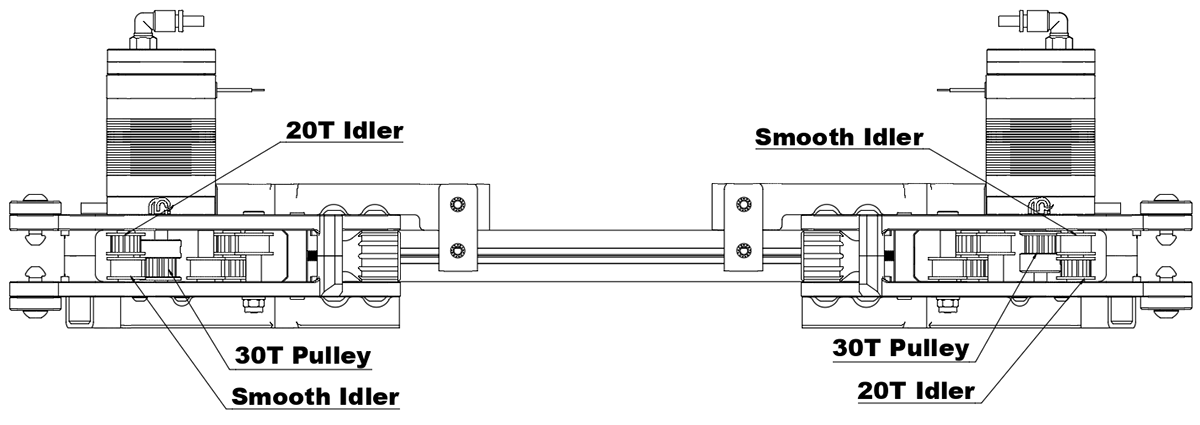
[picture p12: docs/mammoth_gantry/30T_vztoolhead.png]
mammoth-3D Gantry 30T Pulley and VZ Toolhead
||
| All the other idlers remain the same as shown in the image: 20T Pulley / VZ Toolhead. |

| 20T or 30T Pulley / Voron Toolhead |
|:-----------------------------------------------:|
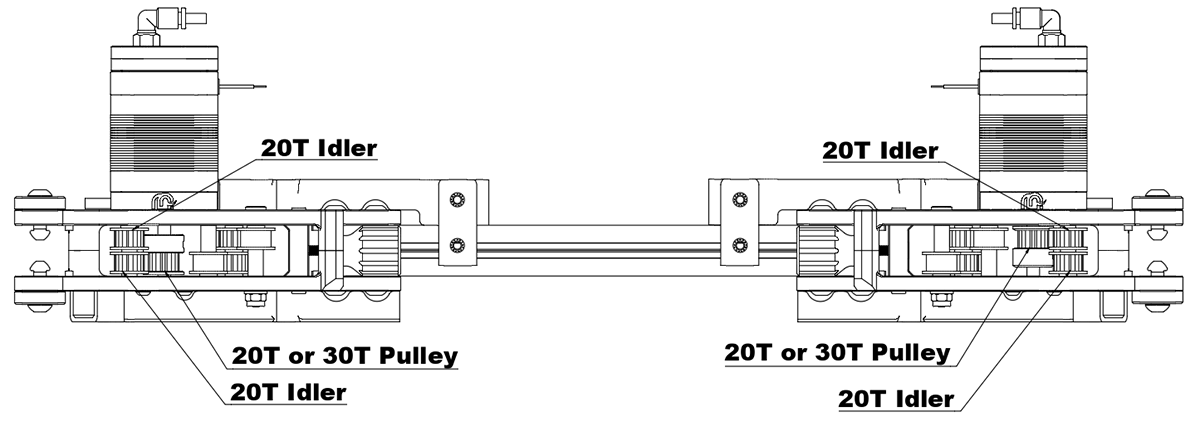
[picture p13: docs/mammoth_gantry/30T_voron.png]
mammoth-3D Gantry 20T or 30T Pulley and Voron Toolhead
||
| All the other idlers remain the same as shown in the image: 20T Pulley / VZ Toolhead. |

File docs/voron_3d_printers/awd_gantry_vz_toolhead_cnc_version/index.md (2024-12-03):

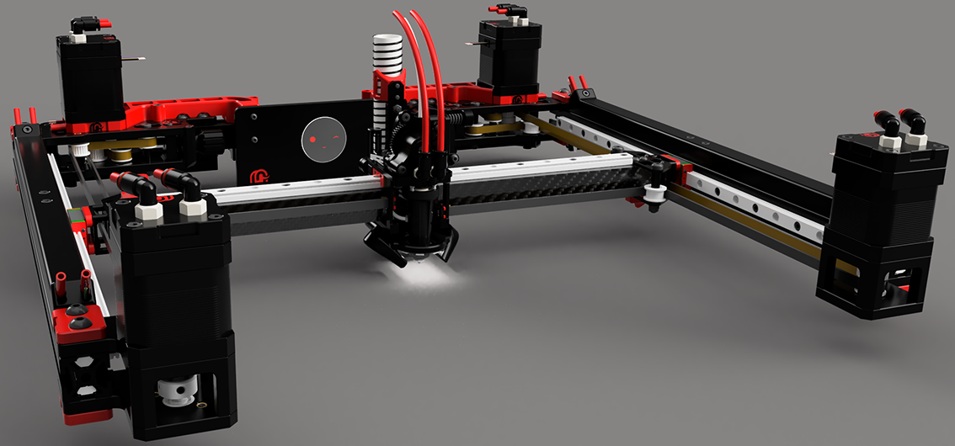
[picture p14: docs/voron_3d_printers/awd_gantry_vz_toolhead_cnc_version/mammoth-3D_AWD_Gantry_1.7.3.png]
mammoth-3D AWD Gantry with VZBOT Toolhead
# **The Voron 2.4 AWD Gantry with VZBOT Toolhead by mammoth-3D** 

**The Voron 2.4 AWD Gantry introduces a groundbreaking design that sets it apart from other all-wheel-drive (AWD) systems available in the market. Here’s what makes it unique.**

**1. Shorter Belt Paths for Greater Efficiency:**

- Unlike other systems, the Mammoth-3D design uses significantly shorter belts. This reduces belt stretch and increases precision, resulting in smoother movement, better print quality, and enhanced reliability.

**2. Reduced Printer Vibrations:**

- The optimized design minimizes vibrations during operation, improving stability and ensuring that prints are free of artifacts. This reduction in vibrations also allows for better compatibility with advanced features like input shaping, further enhancing print speeds and quality.

**3. Flexible Motor Placement:**

- The system allows motors to be mounted either at the top or bottom of the printer without requiring reprints or additional modifications to any components. This flexibility provides users with customization options to suit their workspace and printing needs.

**4. User-Friendly Design:**

- The design of the tensioner is ergonomic and user-friendly, making it accessible even for those who may not have extensive technical expertise. This helps in making the overall maintenance and adjustment process less intimidating.

**5. Compatibility with Voron 2.4:**

- Specifically designed for the Voron 2.4 3D printer, it fits seamlessly into the existing setup without requiring significant modifications. This ensures that users of Voron 2.4 can easily integrate the AWD Gantry into their printers.

**6. Integrated Cable Management:**

- A comprehensive cable management system is included, keeping the build neat and organized. It simplifies maintenance and ensures that wiring is secure and out of the way, contributing to the system's overall reliability.

**7. Future-Proof Design:**

- The gantry is compatible with upgrades like water cooling, enabling users to enhance their printer’s capabilities without needing to redesign the gantry. This makes it a forward-thinking solution for advanced hobbyists and professionals.

**Why It Stands Out**

By addressing key challenges like belt length, vibration control, and upgrade flexibility, the Mammoth-3D AWD Gantry represents a leap forward in 3D printer gantry systems. It combines mechanical innovation with practical design considerations, offering users improved performance and adaptability over other systems in the market.

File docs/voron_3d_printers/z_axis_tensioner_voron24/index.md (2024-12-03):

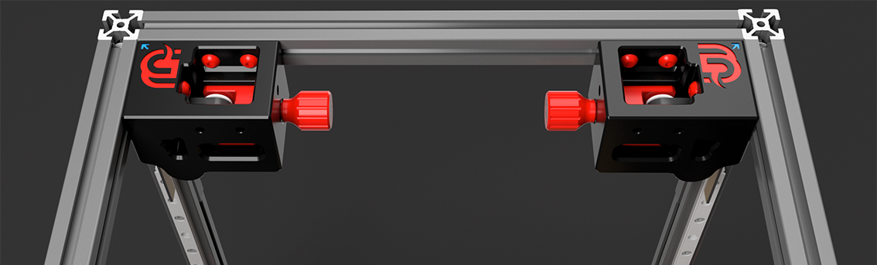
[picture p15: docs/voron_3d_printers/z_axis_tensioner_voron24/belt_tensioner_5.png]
Tool-free Z-Axis Belt Tensioner for Voron 2.4 3D Printers by mammoth-3D
# **The Tool-free Z-Axis Belt Tensioner for Voron 2.4 3D Printers by Mammoth-3D is unique due to several key features:** 

**1. Tool-Free Adjustment:**

- The primary innovation of this tensioner is the ability to adjust the belt tension without the need for any tools. This convenience allows for quick and easy adjustments, saving time and simplifying the process for users.

**2. Dual Functionality:**

- It's not only a Z-Axis Belt Tensioner but also serves as a top brace, which improves input shaper results. This dual functionality enhances the overall stability and precision of the 3D printer, leading to better performance and print quality.

**3. Precision and Reliability:**

- It offers precise tension control, which is crucial for maintaining print quality and accuracy. Proper tension ensures that the printer operates smoothly and consistently, reducing the chances of print failures or inconsistencies.

**4. User-Friendly Design:**

- The design of the tensioner is ergonomic and user-friendly, making it accessible even for those who may not have extensive technical expertise. This helps in making the overall maintenance and adjustment process less intimidating.

**5. Compatibility with Voron 2.4:**

- Specifically designed for the Voron 2.4 3D printer, it fits seamlessly into the existing setup without requiring significant modifications. This ensures that users of Voron 2.4 can easily integrate the tensioner into their printers.

**6. Excellent Design:**

- Mammoth-3D products are known for their high-quality materials and robust construction. The belt tensioner features an excellent design that ensures durability and long-lasting performance, providing reliable operation over time.

**7. Enhanced Print Performance:**

- By maintaining optimal belt tension, the tool-free tensioner contributes to improved print quality. It helps in minimizing issues like layer shifting and print artifacts, leading to cleaner and more precise prints.

**8. Innovative Mechanism:**

- The mechanism employed for tension adjustment might involve innovative engineering solutions that make the adjustment process not only tool-free but also smooth and secure, preventing accidental loosening or overtightening.

These features collectively make the Tool-free Z-Axis Belt Tensioner by Mammoth-3D a valuable upgrade for Voron 2.4 3D printers, enhancing usability, performance, and reliability.

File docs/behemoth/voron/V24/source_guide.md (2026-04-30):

# **Mellow-3D behemoth - Voron 2.4 - Bill of material**

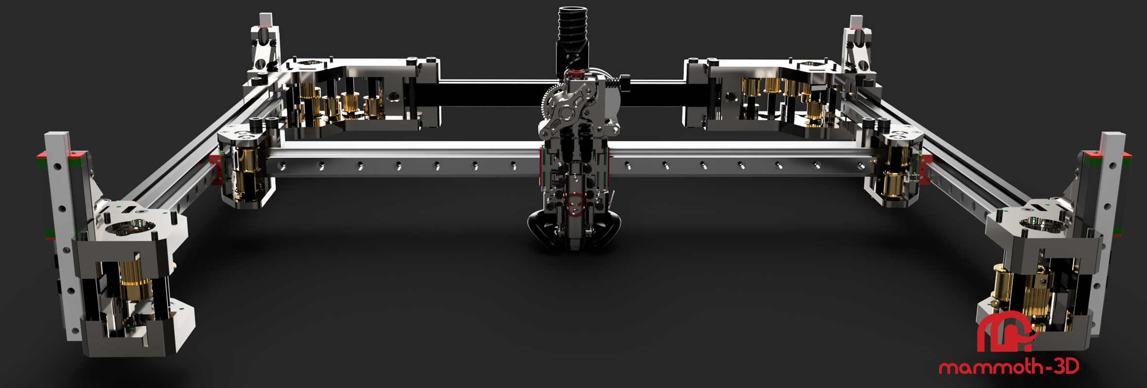
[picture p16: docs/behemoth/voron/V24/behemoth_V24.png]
behemoth AWD Gantry for Voron 2.4


---

## Version: 1.00 / 25.04.2026

---

## behemoth - Set1: X1 & Y1 Motor Mount

### Aluminium Parts
| **Quantity** | **Description** |**Link** |
|:---|---|---:|
| 1x | **SET 1 - behemoth X1 top motor mount** |[Mellow 3D](https://de.aliexpress.com/item/33023133633.html?) |
| 1x | **SET 1 - behemoth X1 bottom motor mount** | |
| 1x | **SET 1 - behemoth Y1 top motor mount** | |
| 1x | **SET 1 - behemoth Y1 bottom motor mount** | |

### Screws
| **Quantity** | **Description** |
|:---|---:|
| 4x | **M3x5mm SHCS** |
| 14x | **M3x6mm SHCS** |
| 2x | **M3x10mm SHCS** |
| 6x | **M3x55mm SHCS** |
| 4x | **M5x15mm SHCS** |
| 16x | **M5x20mm SHCS** |
| 2x | **Sholder bolt 50mm**: Shoulder Diameter (d) 5mm / Thread Size 4mm |

### Flanged Ball Bearings
| **Quantity** | **Description** |
|:---|---:|
| 2x | **625** for 5mm Motor Shaft|
| 2x | **688** for 8mm Motor Shaft **NOT INCLUDED IN THE KIT**|

### Aluminium Bushings
| **Quantity** | **Description** |
|:---|---:|
| 6x | **M3 Bushing** 3.1mm ID x 6mm OD x 30mm |

### Drop-in T-nut
| **Quantity** | **Description** |
|:---|---:|
| 20x | **M5 T-nut** |

## behemoth - Set2: X & Y Motor Mount

### Aluminium Parts
| **Quantity** | **Description** |**Link** |
|:---|---|---:|
| 1x | **SET 2 - behemoth X top motor mount** |[Mellow 3D](https://de.aliexpress.com/item/33023133633.html?) |
| 1x | **SET 2 - behemoth X bottom motor mount** | |
| 1x | **SET 2 - behemoth Y top motor mount** | |
| 1x | **SET 2 - behemoth Y bottom motor mount** | |

### Screws
| **Quantity** | **Description** |
|:---|---:|
| 4x | **M3x5mm SHCS** |
| 6x | **M3x6mm SHCS** |
| 2x | **M3x10mm SHCS** |
| 6x | **M3x55mm SHCS** |
| 4x | **M5x15mm SHCS** |
| 8x | **M5x20mm SHCS** |

### Flanged Ball Bearings
| **Quantity** | **Description** |
|:---|---:|
| 2x | **625** for 5mm Motor Shaft|
| 2x | **688** for 8mm Motor Shaft **NOT INCLUDED IN THE KIT**|

### Aluminium Bushings
| **Quantity** | **Description** |
|:---|---:|
| 6x | **M3 Bushing** 3.1mm ID x 6mm OD x 30mm |

### Drop-in T-nut
| **Quantity** | **Description** |
|:---|---:|
| 12x | **M5 T-nut** |

## behemoth - Set3: X1 & Y1 Idler Pack

### Aluminium Parts
| **Quantity** | **Description** |**Link** |
|:---|---|---:|
| 1x | **SET 3 - behemoth X1 top idler pack** |[Mellow 3D](https://de.aliexpress.com/item/33023133633.html?) |
| 1x | **SET 3 - behemoth X1 bottom idler pack** | |
| 1x | **SET 3 - behemoth Y1 top idler pack** | |
| 1x | **SET 3 - behemoth Y1 bottom idler pack** | |
| 2x | **SET 3 - behemoth Y1 bottom idler pack brace** | |

### Screws
| **Quantity** | **Description** |
|:---|---:|
| 2x | **M2x10mm SHCS** |
| 4x | **Low-Profile M3x8mm** |

### Flanged Ball Bearings
| **Quantity** | **Description** |
|:---|---:|
| 16x | **MF115ZZ** for 5mm Live Idler Shaft |

## behemoth - Set4: Idler Pack Tension Arms

### Aluminium Parts
| **Quantity** | **Description** |**Link** |
|:---|---|---:|
| 2x | **SET 4 - behemoth idler pack tension arm** |[Mellow 3D](https://de.aliexpress.com/item/33023133633.html?) |

### Screws
| **Quantity** | **Description** |
|:---|---:|
| 2x | **M4x25mm SHCS** |

### Flanged Ball Bearings
| **Quantity** | **Description** |
|:---|---:|
| 4x | **MF115ZZ** for 5mm Live Idler Shaft |

### h6 Precision dowel pins
| **Quantity** | **Description** |
|:---|---:|
| 2x | h6 Precision dowel pins **M5x45mm** |

### Precision shims
| **Quantity** | **Description** |
|:---|---:|
| 4x | Precision shims **M5x7x1mm** |

### Cross Hole Hammer Nuts
| **Quantity** | **Description** |
|:---|---:|
| 2x | **M4x25mm** Hammer Nut |

## behemoth - Set5: X & Y Idler Pack

### Aluminium Parts
| **Quantity** | **Description** |**Link** |
|:---|---|---:|
| 1x | **SET 5 - behemoth X top idler pack** |[Mellow 3D](https://de.aliexpress.com/item/33023133633.html?) |
| 1x | **SET 5 - behemoth X bottom idler pack** | |
| 1x | **SET 5 - behemoth Y top idler pack** | |
| 1x | **SET 5 - behemoth Y bottom idler pack** | |

### Flanged Ball Bearings
| **Quantity** | **Description** |
|:---|---:|
| 4x | **MF115ZZ** for 5mm Live Idler Shaft |

## behemoth - Set6: XY Joiners

### Aluminium Parts
| **Quantity** | **Description** |**Link** |
|:---|---|---:|
| 1x | **SET 6 - behemoth XY-joiner A top** |[Mellow 3D](https://de.aliexpress.com/item/33023133633.html?) |
| 1x | **SET 6 - behemoth XY-joiner A bottom** | |
| 2x | **SET 6 - behemoth XY-joiner AB middle** | |
| 1x | **SET 6 - behemoth XY-joiner B top** | |
| 1x | **SET 6 - behemoth XY-joiner B bottom** | |

### Screws
| **Quantity** | **Description** |
|:---|---:|
| 8x | **Low-Profile M3x5mm** |
| 8x | **Low-Profile M3x8mm** |
| 6x | **M5x18mm SHCS** |

### Flanged Ball Bearings
| **Quantity** | **Description** |
|:---|---:|
| 8x | **MF115ZZ** for 5mm Live Idler Shaft |

!!! tip
    **X-axis SET7 and SET8 are ideal for high-speed 3D printing and chamber temperatures up to 60 °C. If you’re looking for a high-temperature (up to 100C) X-axis, choose SET9–SET11 depending on your 3D printer size.**

## behemoth - Set7: High Speed X-axis for Voron 300

### Aluminium Parts
| **Quantity** | **Description** |**Link** |
|:---|---|---:|
| 1x | **SET 7 - behemoth 300 X axis high-speed** |[Mellow 3D](https://de.aliexpress.com/item/33023133633.html?) |

## behemoth - Set8: High Speed X-axis for Voron 350

### Aluminium Parts
| **Quantity** | **Description** |**Link** |
|:---|---|---:|
| 1x | **SET 8 - behemoth 350 X axis high-speed** |[Mellow 3D](https://de.aliexpress.com/item/33023133633.html?) |

## behemoth - Set9: High-temperature X-axis for Voron 300

### Stainless steel Parts
| **Quantity** | **Description** |**Link** |
|:---|---|---:|
| 1x | **SET 9 - behemoth 300 X axis high-temp** |[Mellow 3D](https://de.aliexpress.com/item/33023133633.html?) |

## behemoth - Set10: High-temperature X-axis for Voron 350

### Stainless steel Parts
| **Quantity** | **Description** |**Link** |
|:---|---|---:|
| 1x | **SET 10 - behemoth 350 X axis high-temp** |[Mellow 3D](https://de.aliexpress.com/item/33023133633.html?) |

## behemoth - Set11: High-temperature X-axis for Voron 400

### Stainless steel Parts
| **Quantity** | **Description** |**Link** |
|:---|---|---:|
| 1x | **SET 11 - behemoth 400 X axis high-temp** |[Mellow 3D](https://de.aliexpress.com/item/33023133633.html?) |

!!! warning
    Please note that you are ordering **SET12 – Behemoth V24 Fixed Z Joints**. 

    **SET13**, designed for **VT** 3D printers, will not fit.

## behemoth - Set12: V24 Fixed Z Joints

### Aluminium Parts
| **Quantity** | **Description** |**Link** |
|:---|---|---:|
| 2x | **SET 12 - behemoth V24 Fixed Z Joints A1** |[Mellow 3D](https://de.aliexpress.com/item/33023133633.html?) |
| 2x | **SET 12 - behemoth V24 Fixed Z Joints A2** | |
| 2x | **SET 12 - behemoth V24 Fixed Z Joints B1** | |
| 2x | **SET 12 - behemoth V24 Fixed Z Joints B2** | |

### Screws
| **Quantity** | **Description** |
|:---|---:|
| 16x | **M3x6mm SHCS** |

!!! warning
    Before ordering live idlers for your 3D printer, confirm whether your build uses 9 mm or 12 mm belts. The live idlers are press-fitted and difficult to replace, so choosing the correct size is important. If you order the wrong version, you will need to purchase the correct one.

    **SET14 and SET15 are designed for 9 mm belts.**

    **SET16 and SET17 are designed for 12 mm belts.**

## behemoth - Set14: Live Idler 9mm with teeth

### Live Idler
| **Quantity** | **Description** |**Link** |
|:---|---|---:|
| 6x | **SET 14 - behemoth live idler 9mm with teeth** |[Mellow 3D](https://de.aliexpress.com/item/33023133633.html?) |

## behemoth - Set15: Live Idler 9mm without teeth

### Live Idler
| **Quantity** | **Description** |**Link** |
|:---|---|---:|
| 8x | **SET 15 - behemoth live idler 9mm without teeth** |[Mellow 3D](https://de.aliexpress.com/item/33023133633.html?) |

## behemoth - Set16: Live Idler 12mm with teeth

### Live Idler
| **Quantity** | **Description** |**Link** |
|:---|---|---:|
| 6x | **SET 16 - behemoth live idler 12mm with teeth** |[Mellow 3D](https://de.aliexpress.com/item/33023133633.html?) |

## behemoth - Set17: Live Idler 12mm without teeth

### Live Idler
| **Quantity** | **Description** |**Link** |
|:---|---|---:|
| 8x | **SET 17 - behemoth live idler 12mm without teeth** |[Mellow 3D](https://de.aliexpress.com/item/33023133633.html?) |

!!! warning
    Please note before ordering: the behemoth use **brass pulleys** for increased strength and reduced wear compared to aluminum. **Aluminum pulleys** are still supported if you prefer that option.

    The gantry supports **9 mm and 12 mm** belts, as well as **5 mm or 8 mm** motor shafts. Please confirm your motor shaft size and belt width before placing your order.

## behemoth - Set18: Brass M5x9mm belt pulley

### Brass pulley
| **Quantity** | **Description** |**Link** |
|:---|---|---:|
| 4x | **SET 18 - behemoth brass M5x9mm belt pulley** |[Mellow 3D](https://de.aliexpress.com/item/33023133633.html?) |

## behemoth - Set19: Brass M5x12mm belt pulley

### Brass pulley
| **Quantity** | **Description** |**Link** |
|:---|---|---:|
| 4x | **SET 19 - behemoth brass M5x12mm belt pulley** |[Mellow 3D](https://de.aliexpress.com/item/33023133633.html?) |

## behemoth - Set20: Brass M8x9mm belt pulley

### Brass pulley
| **Quantity** | **Description** |**Link** |
|:---|---|---:|
| 4x | **SET 20 - behemoth brass M8x9mm belt pulley** |[Mellow 3D](https://de.aliexpress.com/item/33023133633.html?) |

## behemoth - Set21: Brass M8x12mm belt pulley

### Brass pulley
| **Quantity** | **Description** |**Link** |
|:---|---|---:|
| 4x | **SET 21 - behemoth brass M8x12mm belt pulley** |[Mellow 3D](https://de.aliexpress.com/item/33023133633.html?) |

## behemoth - Set22: behemoth Toolhead for MGN9H and MGN12H

### Aluminium Parts
| **Quantity** | **Description** |**Link** |
|:---|---|---:|
| 1x | **SET 22 - behemoth Toolhead Back Plate** |[Mellow 3D](https://de.aliexpress.com/item/33023133633.html?) |
| 1x | **SET 22 - behemoth Toolhead Top Plate** | |
| 1x | **SET 22 - behemoth CPAP Duct Slider** | |

### Screws
| **Quantity** | **Description** |
|:---|---:|
| 2x | **M2x10mm SHCS** |
| 2x | **M3x3mm SHCS** |
| 8x | **M3x6mm SHCS** |
| 4x | **Low-Profile M3x6mm** |
| 4x | **M3x8mm SHCS** |
| 6x | **Low-Profile M3x8mm** |
| 3x | **M3x12mm SHCS** |
| 4x | **M3x16mm SHCS** |
| 4x | **M3x40mm SHCS** |

### Locknut
| **Quantity** | **Description** |
|:---|---:|
| 2x | **M3** Locknut |

### Washer
| **Quantity** | **Description** |
|:---|---:|
| 2x | **M3** Washer |

### Threaded Insert
| **Quantity** | **Description** |
|:---|---:|
| 6x | **M3 Threaded Insert** (M3x5mmx4mm) |

### Aluminium Bushings
| **Quantity** | **Description** |
|:---|---:|
| 2x | **M3 Bushing** 3.1mm ID x 6mm OD x 10mm |
| 4x | **M3 Bushing** 3.1mm ID x 6mm OD x 35mm |

!!! warning
    Before ordering **belt clamps** for your 3D printer, confirm whether your build uses 9 mm or 12 mm belts.

    **SET23 is designed for 9-10 mm belts.**

    **SET24 is designed for 12 mm belts.**

## behemoth - Set23: 9-10mm Belt Clamp

### Laser Cut Stainless Steel
| **Quantity** | **Description** |**Link** |
|:---|---|---:|
| 2x | **SET 23 - behemoth 9-10mm Belt Clamp** |[Mellow 3D](https://de.aliexpress.com/item/33023133633.html?) |

## behemoth - Set24: 12mm Belt Clamp

### Laser Cut Stainless Steel
| **Quantity** | **Description** |**Link** |
|:---|---|---:|
| 2x | **SET 24 - behemoth 12mm Belt Clamp** |[Mellow 3D](https://de.aliexpress.com/item/33023133633.html?) |

!!! tip
    The **behemoth Toolhead** is specifically designed for use with the **mammoth-3D Hell Fire Hotend**. However, it can also support other hotends when used with the universal adapter.

    Please review the following options carefully before placing your order:

    **Set 25: Designed exclusively for the Hell Fire Hotend** and is not compatible with other hotends.

    **Set 26**: Includes the **universal hotend plate**, allowing compatibility with a range of hotends such as the **Rapido, Goliath Air, Goliath Water, and Tricorn hotends**.

    Note: **The Chube** Hotend is currently not supported.

## behemoth - Set25: Hell Fire Water cooling Plate / Mounting Plate

### Aluminium Parts
| **Quantity** | **Description** |**Link** |
|:---|---|---:|
| 1x | **SET 25 - behemoth Hotend Water Block** |[Mellow 3D](https://de.aliexpress.com/item/33023133633.html?) |
| 1x | **SET 25 - behemoth Hell Fire Hotend Mount** | |

### Screws
| **Quantity** | **Description** |
|:---|---:|
| 4x | **Heat Break Screws** |
| 4x | **Heat Break Nuts** |

### Bearings
| **Quantity** | **Description** |
|:---|---:|
| 1x | **3mm** Bearing |

### Press fit adapter
| **Quantity** | **Description** |
|:---|---:|
| 2x | **Press fit adapter** for 2mm ID x 4mm OD |

## behemoth - Set26: Universal Hotend Plate and Duct Mounting Plate

### Aluminium Parts
| **Quantity** | **Description** |**Link** |
|:---|---|---:|
| 1x | **SET 26 - behemoth Universal Duct Plate** |[Mellow 3D](https://de.aliexpress.com/item/33023133633.html?) |
| 1x | **SET 26 - behemoth Universal Hotend Plate** | |

## mammoth-3D - Set28: Hell Fire Hotend 150 Watt

### Hell Fire Hotend
| **Quantity** | **Description** |**Link** |
|:---|---|---:|
| 1x | **SET 28 - Hell Fire Hotend** |[Mellow 3D](https://de.aliexpress.com/item/33023133633.html?) |

### Thermistor
| **Quantity** | **Description** |
|:---|---:|
| 1x | **550C Thermistor** |

### Screws
| **Quantity** | **Description** |
|:---|---:|
| 2x | **M2x3mm SHCS** |

### SLM Titanium Shield
| **Quantity** | **Description** |
|:---|---:|
| 1x | **Hell Fire Shiel** |

### Heat Brak
| **Quantity** | **Description** |
|:---|---:|
| 1x | **Hell Fire Heat Break** |
| 1x | **Hell Fire Heat Break Cover** |

### Kevlar Sock
| **Quantity** | **Description** |
|:---|---:|
| 1x | **Hell Fire Kevlar Sock** |

### V6 Nozzle
| **Quantity** | **Description** |
|:---|---:|
| 1x | **0.4mm V6 Nozzle** |

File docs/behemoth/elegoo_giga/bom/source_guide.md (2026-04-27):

# **Elegoo Orange Storm Giga - Bill of material**

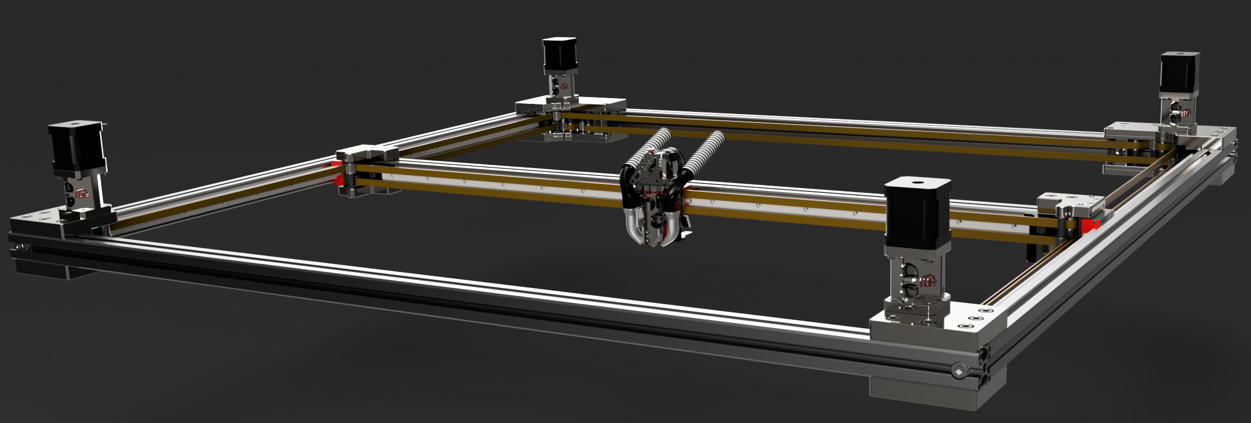
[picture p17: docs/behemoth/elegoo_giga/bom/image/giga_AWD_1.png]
Elegoo Orange Storm Giga with behemoth AWD Gantry


---

## Version: 1.10 / 18.04.2026

---

### Idlers
| **Quantity** | **Description** | **Standard** | **Link1** | **Link2** | **Link3** |
|:---|---|---|---|---|---:|
| 8x | **GT2 Smooth Idle** / Bore 5mm for 9mm belts (14/11) | Aluminium |[Mellow 3D](https://de.aliexpress.com/item/33023133633.html?) | [McMaster](https://www.mcmaster.com/3693N15/) | [Fabreeko](https://www.fabreeko.com/collections/honeybadger/products/2mgt-toothed-pulleys-idlers-by-fabreeko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) |
| 6x | **GT2 20 Tooth Idler** / Bore 5mm for 9mm belts (14/11) | Aluminium |[Mellow 3D](https://de.aliexpress.com/item/33023133633.html?) | [McMaster](https://www.mcmaster.com/3693N12/) | [Fabreeko](https://www.fabreeko.com/collections/honeybadger/products/2mgt-toothed-pulleys-idlers-by-fabreeko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) |

### Pulleys
| **Quantity** | **Description** | **Standard** | **Link1** | **Link2** | **Link3** |
|:---|---|---|---|---|---:|
| 4x | **GT2 20 Tooth Pulley** / Bore 5mm for 9mm belts | Aluminium |[Mellow 3D](https://de.aliexpress.com/item/33023279793.html?) | [KB3D](https://kb-3d.com/store/motion/250-gates-powergrip-2gt-pulley-20-tooth-5mm-9mm-1634481732885.html) | [Fabreeko](https://www.fabreeko.com/collections/honeybadger/products/2mgt-toothed-pulleys-idlers-by-fabreeko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) |

!!! warning
    This MOD was made for 14/11mm Pulleys. Please check before 
    using different once.

### Bearings
| **Quantity** | **Description** | **Standard** | **Link1** | **Link2** |
|:---|---|---|---|---:|
| 8x | Steel Flanged Ball Bearing, Shielded, Trade: **F625-2Z** | Steel |[Aliexpress](https://de.aliexpress.com/item/1005008106295541.html?) | [McMaster](https://www.mcmaster.com/57155K579/) |
| 4x | Steel Flanged Ball Bearing, Shielded, Trade: **F115-2Z** | Steel |[Aliexpress](https://de.aliexpress.com/item/1005008107488825.html?) | [McMaster](https://www.mcmaster.com/57155K571/) |

### h6 Precision dowel pins
| **Quantity** | **Description** | **Standard** | **Link1** | **Link2** | **Link3** |
|:---|---|---|---|---|---:|
| 16x | h6 Precision dowel pins **M5x45mm** | Steel |[Aliexpress](https://de.aliexpress.com/item/1005010026576161.html?) | [BRW](https://www.brw.ch/en-CH/precision-dowel-pins-tolerance-h6-861660?attr_50512_I6=5&page=1#) | [McMaster](https://www.mcmaster.com/products/precision-dowel-pins/diameter~5-0000-mm/diameter~5-000-mm/diameter~5-mm/length~45-mm/) |
| 4x  | h6 Precision dowel pins **M5x75mm** | Steel |[Aliexpress](https://de.aliexpress.com/item/1005010026576161.html?) | [BRW](https://www.brw.ch/en-CH/precision-dowel-pins-tolerance-h6-861660?attr_50512_I6=5&page=1#) | [McMaster](https://www.mcmaster.com/products/precision-dowel-pins/diameter~5-0000-mm/diameter~5-000-mm/diameter~5-mm/length~80-mm/) |

### Screws
| **Quantity** | **Description** | **Standard** | **Link1** | **Link2** | **Link3** |
|:---|---|---|---|---|---:|
| 4x | **M2x10 SHCS** | ISO 4762 / DIN 912 |[Bolt Depot](https://boltdepot.com/Product-Details?product=6365) | [McMaster](https://www.mcmaster.com/91292A833/) | [Aliexpress](https://de.aliexpress.com/item/1005007318253599.html?) |
| 2x | **M3x4 SHCS**  | ISO 4762 / DIN 912 |[Bolt Depot](https://boltdepot.com/Product-Details?product=6360) | [McMaster](https://www.mcmaster.com/91292A109/) | [Aliexpress](https://de.aliexpress.com/item/1005007318253599.html?) |
| 48x | **M3x8 SHCS**  | ISO 4762 / DIN 912 |[Bolt Depot](https://boltdepot.com/Product-Details?product=6379) | [McMaster](https://www.mcmaster.com/91292A112) | [Aliexpress](https://de.aliexpress.com/item/1005007318253599.html?) |
| 19x | **M3x12 SHCS** | ISO 4762 / DIN 912 |[Bolt Depot](https://boltdepot.com/Product-Details?product=6381) | [McMaster](https://www.mcmaster.com/91292A114/) | [Aliexpress](https://de.aliexpress.com/item/1005007318253599.html?) |
| 4x | **M3x16 SHCS** | ISO 4762 / DIN 912 |[Bolt Depot](https://boltdepot.com/Product-Details?product=6382) | [McMaster](https://www.mcmaster.com/91292A115/) | [Aliexpress](https://de.aliexpress.com/item/1005007318253599.html?) |
| 4x | **M3x55 SHCS** | ISO 4762 / DIN 912 | | [McMaster](https://www.mcmaster.com/91292A314/) | [Aliexpress](https://de.aliexpress.com/item/1005005347191323.html?) |
| 12x  | **M3x65 SHCS** | ISO 4762 / DIN 912 | | [McMaster](https://www.mcmaster.com/91292A315/) | [Aliexpress](https://de.aliexpress.com/item/1005005347191323.html?) |
| 7x  | **Low Profile M3x6** | ISO 4762 / DIN 912 | | [McMaster](https://www.mcmaster.com/91223A412/) | [Aliexpress](https://de.aliexpress.com/item/1005006209329445.html?) |
| 8x  | **Low Profile M3x8** | ISO 4762 / DIN 912 | | [McMaster](https://www.mcmaster.com/91223A413/) | [Aliexpress](https://de.aliexpress.com/item/1005006209329445.html?) |
| 45x  | **M4x16 SHCS** | ISO 4762 / DIN 912 |[Bolt Depot](https://boltdepot.com/Product-Details?product=6396) | [McMaster](https://www.mcmaster.com/91292A118/) | [Aliexpress](https://de.aliexpress.com/item/1005007318253599.html) |
| 2x  | **M4x25 SHCS** | ISO 4762 / DIN 912 |[Bolt Depot](https://boltdepot.com/Product-Details?product=6399) | [McMaster](https://www.mcmaster.com/91292A122/) | [Aliexpress](https://de.aliexpress.com/item/1005007318253599.html) |
| 12x | **Low Profile M4x10** | ISO 4762 / DIN 912 | | [McMaster](https://www.mcmaster.com/91223A419/) | [Aliexpress](https://de.aliexpress.com/item/1005006209329445.html?) |
| 54x | **M6x16 SHCS** | ISO 4762 / DIN 912 |[Bolt Depot](https://boltdepot.com/Product-Details?product=6418) | [McMaster](https://www.mcmaster.com/91292A135/) | [Aliexpress](https://de.aliexpress.com/item/1005001597704601.html?) |
| 4x | **M8x60 SHCS** | ISO 4762 / DIN 912 |[Bolt Depot](https://boltdepot.com/Product-Details?product=6442) | [McMaster](https://www.mcmaster.com/91292A209/) | [Aliexpress](https://de.aliexpress.com/item/1005010060577575.html?) |

### Sholder bolts
| **Quantity** | **Description** | **Standard** | **Link1** | **Link2** | **Link3** |
|:---|---|---|---|---|---:|
| 2x | **Sholder bolt 50mm**: Shoulder Diameter (d) 5mm / Thread Size 4mm | ISO 4762 / DIN 912 | [Bolt Depot](https://boltdepot.com/Product-Details?product=20390) | [McMaster](https://www.mcmaster.com/90269A232/) | [Aliexpress](https://de.aliexpress.com/item/1005003335259903.html?) |

### Bushings
| **Quantity** | **Description** | **Standard** | **Link1** | **Link2** | **Link3** |
|:---|---|---|---|---|---:|
| 12x | Bushing **M3x6x30mm** | ISO 4762 / DIN 912 | [Aliexpress](https://de.aliexpress.com/item/1005007047100632.html?) | [Aliexpress](https://de.aliexpress.com/item/4000313338516.html?) | [Aliexpress](https://de.aliexpress.com/item/1005009828339139.html?) |
| 14x| Bushing **M5x8x20mm** | ISO 4762 / DIN 912 | [Aliexpress](https://de.aliexpress.com/item/1005007047100632.html?) | [Aliexpress](https://de.aliexpress.com/item/1005007709702495.html?) | [Aliexpress](https://de.aliexpress.com/item/1005010464521327.html?) |

### Precision shims
| **Quantity** | **Description** | **Standard** | **Link1** | **Link2** | **Link3** | 
|:---|---|---|---|---|---:|
| 28x | Precision shims **M5x7x0.5mm** | ISO 4762 / DIN 912 | [Fabreeko](https://www.fabreeko.com/products/m5-precision-brass-shims-m5x7x0-5?_pos=1&_psq=Precision+shims&_ss=e&_v=1.0) | [KB3D](https://kb-3d.com/store/inserts-fasteners-adhesives/508-5x7x05mm-shim-ring-washer-pack-of-50-din988-1634423113147.html) | [Aliexpress](https://de.aliexpress.com/item/1005010042779749.html?) |
| 18x| Precision shims **M5x7x1mm** | ISO 4762 / DIN 912 | [XRAY](https://www.eurorc.com/product/33229/xray-alu-shim-5x7x10mm-10) | [KB3D](https://kb-3d.com/store/inserts-fasteners-adhesives/5516-5x6x1mm-shim-ring-washer-pack-of-50-din988-1635423115610.html) | [Aliexpress](https://de.aliexpress.com/item/1005009611490220.html?) |

!!! tip
    **If you can not find M5x7x1mm Precision shims, just get 36x M5x7x0.5mm extra.**

### 30 Series: T Spring Nuts
| **Quantity** | **Description** | **Standard** | **Link1** | **Link2** | **Link3** |
|:---|---|---|---|---|---:|
| 45x | **M4** T-Nut | ISO 4762 / DIN 912 | [Aliexpress](https://de.aliexpress.com/item/1005004662302085.html?) | [McMaster](https://www.mcmaster.com/products/tee-nuts/t-slotted-framing-fasteners-2~/thread-size~m4-1/rail-height~30-mm/) | [Amazon](https://www.amazon.com/Best-Sellers-T-Slot-Nuts/zgbs/industrial/16410141) |
| 54x | **M6** T-Nut | ISO 4762 / DIN 912 | [Aliexpress](https://de.aliexpress.com/item/1005004662302085.html?) | [McMaster](https://www.mcmaster.com/products/tee-nuts/locking-slotted-framing-nuts-2~/thread-size~m6-2/) | [Amazon](https://www.amazon.com/Best-Sellers-T-Slot-Nuts/zgbs/industrial/16410141) |

### Threaded Insert
| **Quantity** | **Description** | **Standard** | **Link1** | **Link2** | **Link3** | **Link4** |
|:---|---|---|---|---|---|---:|
| 2x | **M2 Threaded Insert** (M2x3.6mmx3mm) | Brass | []() | [Fabreeko](https://www.fabreeko.com/products/cnc-kitchen-heat-inserts-m2-m8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) | [KB3D](https://kb-3d.com/store/inserts-fasteners-adhesives/927-7998-cnckitchen-lead-cadmium-free-heat-set-inserts-multiple-sizes-metric.html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) | [CNC Kitchen](https://cnckitchen.store/products/heat-set-insert-m2-x-3-100-pieces) |
| 54x | **M3 Threaded Insert** (M3x5mmx4mm)  | Brass | [ruthex](https://www.amazon.de/ruthex-Gewindeeinsatz-VORON-Gewindebuchsen-Kunststoffteile/dp/B0CDH36ZMX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) | [Fabreeko](https://www.fabreeko.com/products/cnc-kitchen-heat-inserts-m2-m8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) | [KB3D](https://kb-3d.com/store/inserts-fasteners-adhesives/927-8002-cnckitchen-lead-cadmium-free-heat-set-inserts-multiple-sizes-metric.html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) | [CNC Kitchen](https://cnckitchen.store/products/made-for-voron-gewindeeinsatz-threaded-insert-m3x5x4-100-stk-pcs) |
| 2x | **M4 Threaded Insert** (M4x6.3mmx4mm) | Brass  | []() | [Fabreeko](https://www.fabreeko.com/products/cnc-kitchen-heat-inserts-m2-m8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) | [KB3D](https://kb-3d.com/store/inserts-fasteners-adhesives/927-8003-cnckitchen-lead-cadmium-free-heat-set-inserts-multiple-sizes-metric.html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) | [CNC Kitchen](https://cnckitchen.store/products/heat-set-insert-m4-x-4-short-version-100-pieces) |

### Couplers
| **Quantity** | **Description** | **Standard** | **Link1** | **Link2** | **Link3** |
|:---|---|---|---|---|---:|
| 4x | **M5-M5** Coupler | Aluminium | [Amazon](https://www.amazon.com/Sinoblu-Coupling-Aluminum-Flexible-Connector/dp/B096D844MZ?ref_=ast_slp_dp&th=1) | [Fabreeko](https://www.fabreeko.com/products/gtc-19x26-high-vibration-damping-rubber-coupling?_pos=1&_sid=14baa8109&_ss=r) | [Aliexpress](https://de.aliexpress.com/item/1005004537386747.html?) |

### Cross Hole Hammer Nuts
| **Quantity** | **Description** | **Standard** | **Link1** | **Link2** | **Link3** |
|:---|---|---|---|---|---:|
| 2x | **M4x25mm** Hammer Nut | ISO 4762 / DIN 912m | [Amazon](https://www.amazon.com/-/he/dp/B0G3QT7X1K?th=1) | [Aliexpress](https://de.aliexpress.com/item/1005008391022548.html?) | [Aliexpress](https://de.aliexpress.com/item/1005009426680772.html?) |

### Washer
| **Quantity** | **Description** | **Standard** | **Link1** | **Link2** | **Link3** |
|:---|---|---|---|---|---:|
| 2x | **M3** Washer | ISO 4762 / DIN 912 | [Bolt Depot](https://boltdepot.com/Product-List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) | [McMaster](https://www.mcmaster.com/products/washers/washers-2~/washers-2~washer-type~flat/system-of-measurement~metric/screw-size~m3/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) | [Aliexpress](https://de.aliexpress.com/item/1005007189912344.html?) |

### GATES-LL-2GT Belt
| **Quantity** | **Description** | **Standard** | **Link1** | **Link2** | **Link3** |
|:---|---|---|---|---|---:|
| 8x | **GATES-LL-2GT Belt (9mm wide)** |  GT2  |[Fabreeko](https://www.fabreeko.com/products/gates-gt2-open-belt-ll-2gt-6-9-12-reinforced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) | [KB3D](https://kb-3d.com/store/motion/42-gates-powergrip-2gt-belt-open-9mm-width.html) | [Mellow 3D](https://de.aliexpress.com/item/32952396111.html?) |
| 8x | **GATES-LL-2GT Belt (9mm wide)** |  GT3  |[Fabreeko](https://www.fabreeko.com/products/gates-gt3-open-belt-ll-gt3-6-9-reinforced?_pos=2&_sid=535c2ed50&_ss=r) | [KB3D](https://kb-3d.com/store/motion/1043-gates-powergrip-2mgt-gt3-belt-open-9mm-width-1702961443320.html) | [Mellow 3D](https://de.aliexpress.com/item/1005006856153263.html?) |

### X/Y-Axis 9mm Belt

!!! tip
| X-Axis | Y-Axis |
|:---|---:|
| You will need about 3.9 meter for the x-axis, please order 4 meters. | You will need about 3.9 meter for the y-axis, please order 4 meters. |

### 3030 Aluminium Profile
| **Quantity** | **Description** | **Standard** | **Link1** | **Link2** | **Link3** |
|:---|---|---|---|---|---:|
| 2x | **3030x1093mm** |  Aluminium  |[Misumi](https://us.misumi-ec.com/vona2/detail/110302686450/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) | [myaluprofil](https://www.myaluprofil.de/aluminiumprofil-30x30-nut-6-i-typ-.html) | [Aliexpress](https://de.aliexpress.com/item/1005005037443914.html?) |
| 2x | **3030x974mm** |  Aluminium  |[Misumi](https://us.misumi-ec.com/vona2/detail/110302686450/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) | [myaluprofil](https://www.myaluprofil.de/aluminiumprofil-30x30-nut-6-i-typ-.html) | [Aliexpress](https://de.aliexpress.com/item/1005005037443914.html?) |
| 1x | **3030x966mm** |  Aluminium  |[Misumi](https://us.misumi-ec.com/vona2/detail/110302686450/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) | [myaluprofil](https://www.myaluprofil.de/aluminiumprofil-30x30-nut-6-i-typ-.html) | [Aliexpress](https://de.aliexpress.com/item/1005005037443914.html?) |

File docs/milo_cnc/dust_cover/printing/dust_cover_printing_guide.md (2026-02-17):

# **Printing Guide**

## **Version 1.00 / 24. November 2025**

## **Support and Drilling Out Holes**

No need for that (99% whahahaha) :octicons-heart-fill-24:{ .heart } But maybe you need to cleanup your 3D printed parts.

!!! note "Layer Height and Line Width"
    Some parts have supporting layers to allow unsupported features to be printed successfully. These supports are designed to work at a layer height of **0.2mm**, so they may not be sliced correctly if your layer height is not **0.2mm**.

## **How to print the mammoth-3D Dust Cover**

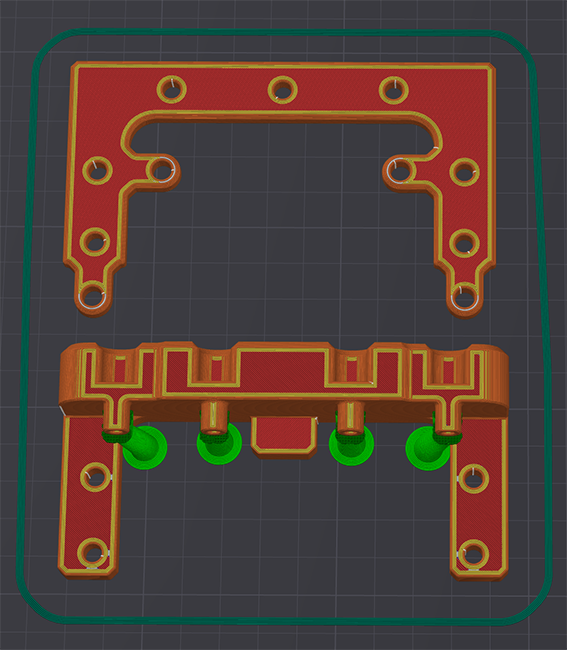
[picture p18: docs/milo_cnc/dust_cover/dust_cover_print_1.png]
How to print the mammoth-3D Dust Cover 1


## **Parts to print**
| **Qty** | **Name** | **Layer hight** | **Wall loops/Min. Wall Thickness** | **Top/Bottom shell layers** |**Infill** | **Material** | **Accent Color** |
|---|---|---|---|---|---|---|-|
| 1x | [X Motor Mount Top](https://www.printables.com/model/1096743-voron-24-mammoth-3d-awd-gantry-v173-x-and-y-motor/files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) | 0.2mm | **5**/2mm | 5 | 85% |ABS/ASA/PA-CF | :material-close: No |
| 1x | [X Motor Mount Bottom](https://www.printables.com/model/1096743-voron-24-mammoth-3d-awd-gantry-v173-x-and-y-motor/files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) | 0.2mm | **5**/2mm | 5 | 85% | ABS/ASA/PA-CF | :material-close: No |
| 1x | [Y Motor Mount Top](https://www.printables.com/model/1096743-voron-24-mammoth-3d-awd-gantry-v173-x-and-y-motor/files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)  | 0.2mm | **5**/2mm | 5 | 85% | ABS/ASA/PA-CF | :material-close: No |
| 1x | [Y Motor Mount Bottom](https://www.printables.com/model/1096743-voron-24-mammoth-3d-awd-gantry-v173-x-and-y-motor/files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)  | 0.2mm | **5**/2mm | 5 | 85% | ABS/ASA/PA-CF | :material-close: No |
| 1x | [X1 Motor Mount Top](https://www.printables.com/model/1097920-voron-24-mammoth-3d-awd-gantry-v173-x1-and-y1-moto/files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)  | 0.2mm | **5**/2mm | 5 | 65% | ABS/ASA | :material-close: No |
| 1x | [X1 Motor Mount Bottom](https://www.printables.com/model/1097920-voron-24-mammoth-3d-awd-gantry-v173-x1-and-y1-moto/files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)  | 0.2mm | **5**/2mm | 5 | 65% | ABS/ASA | :material-close: No |
| 1x | [Y1 Motor Mount Top](https://www.printables.com/model/1097920-voron-24-mammoth-3d-awd-gantry-v173-x1-and-y1-moto/files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)  | 0.2mm | **5**/2mm | 5 | 65% | ABS/ASA | :material-close: No |
| 1x | [Y1 Motor Mount Bottom](https://www.printables.com/model/1097920-voron-24-mammoth-3d-awd-gantry-v173-x1-and-y1-moto/files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)  | 0.2mm | **5**/2mm | 5 | 65% | ABS/ASA | :material-close: No |
| 2x | [Tension Knob](https://www.printables.com/model/1097920-voron-24-mammoth-3d-awd-gantry-v173-x1-and-y1-moto/files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)  | 0.2mm | **4**/1.6mm | 5 | 42% | ABS/ASA | :material-check: Yes |
| 2x | [U ARM](https://www.printables.com/model/1097920-voron-24-mammoth-3d-awd-gantry-v173-x1-and-y1-moto/files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)  | 0.2mm | **4**/1.6mm | 5 | 65% | ABS/ASA | :material-check: Yes |
| 4x | [Voron Belt Clamps](https://www.printables.com/model/1097920-voron-24-mammoth-3d-awd-gantry-v173-x1-and-y1-moto/files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)  | 0.2mm | **4**/1.6mm | 5 | 42% | ABS/ASA | :material-check: Yes |
| 4x | [Bearing Clamp](https://www.printables.com/model/1097920-voron-24-mammoth-3d-awd-gantry-v173-x1-and-y1-moto/files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)  | 0.2mm | **4**/1.6mm | 5 | 42% | ABS/ASA | :material-check: Yes |

!!! tip
    Not everyone uses long shaft motors, and there is no need to change your motors to use the gantry.
    If you are using standard motors in your build, you might consider using bearing covers to close the bearing hole.

## **Bearing Cover**
| **Qty** | **Name** | **Layer hight** | **Wall loops/Min. Wall Thickness** | **Top/Bottom shell layers** |**Infill** | **Material** | **Accent Color** |
|---|---|---|---|---|---|---|-|
| 2x | [Bearing Cover](https://www.printables.com/model/1097920-voron-24-mammoth-3d-awd-gantry-v173-x1-and-y1-moto/files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)  | 0.2mm | **4**/1.6mm | 5 | 42% | ABS/ASA | :material-check: Yes |
| 1x | [Bearing Clamp Logo Right](https://www.printables.com/model/1096743-voron-24-mammoth-3d-awd-gantry-v173-x-and-y-motor/files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)  | 0.2mm | **4**/1.6mm | 5 | 42% | ABS/ASA | :material-check: Yes |
| 1x | [Bearing Clamp Logo Left](https://www.printables.com/model/1096743-voron-24-mammoth-3d-awd-gantry-v173-x-and-y-motor/files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)  | 0.2mm | **4**/1.6mm | 5 | 42% | ABS/ASA | :material-check: Yes |

!!! tip
    Not everyone is interested in an AWD gantry system, so we also offer a 2WD option. The front idler mounts replace the need for the X/Y motor mounts.

### **How to print 2WD gantry parts**

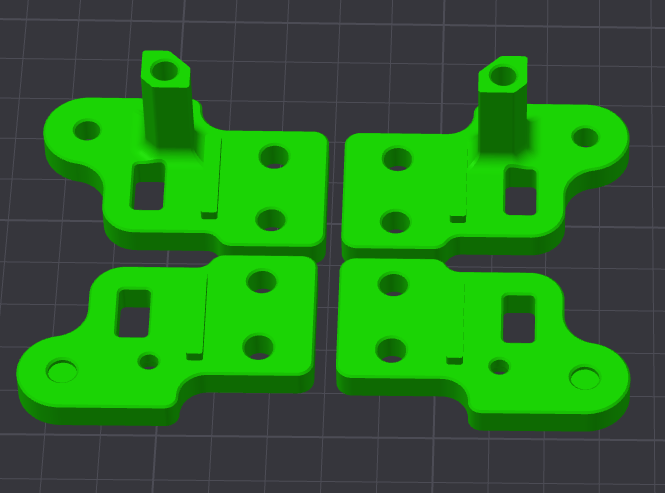
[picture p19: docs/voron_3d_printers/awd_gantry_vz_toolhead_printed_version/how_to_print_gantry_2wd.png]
How to print the mammoth-3D 2WD Gantry parts


## **2WD Parts to print**
| **Qty** | **Name** | **Layer hight** | **Wall loops/Min. Wall Thickness** | **Top/Bottom shell layers** |**Infill** | **Material** | **Accent Color** |
|---|---|---|---|---|---|---|-|
| 1x | [2WD X Top](https://www.printables.com/model/1113851-voron-24-mammoth-3d-2wd-gantry-v173-x-and-y-idler/files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)  | 0.2mm | **4**/1.6mm | 5 | 42% | ABS/ASA/PA-CF | :material-close: No |
| 1x | [2WD X Bottom](https://www.printables.com/model/1113851-voron-24-mammoth-3d-2wd-gantry-v173-x-and-y-idler/files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)  | 0.2mm | **4**/1.6mm | 5 | 42% | ABS/ASA/PA-CF | :material-close: No |
| 1x | [2WD Y Top](https://www.printables.com/model/1113851-voron-24-mammoth-3d-2wd-gantry-v173-x-and-y-idler/files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)  | 0.2mm | **4**/1.6mm | 5 | 42% | ABS/ASA/PA-CF | :material-close: No |
| 1x | [2WD Y Bottom](https://www.printables.com/model/1113851-voron-24-mammoth-3d-2wd-gantry-v173-x-and-y-idler/files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)  | 0.2mm | **4**/1.6mm | 5 | 42% | ABS/ASA/PA-CF | :material-close: No |

### **How to print motor cable routing and water cooling**

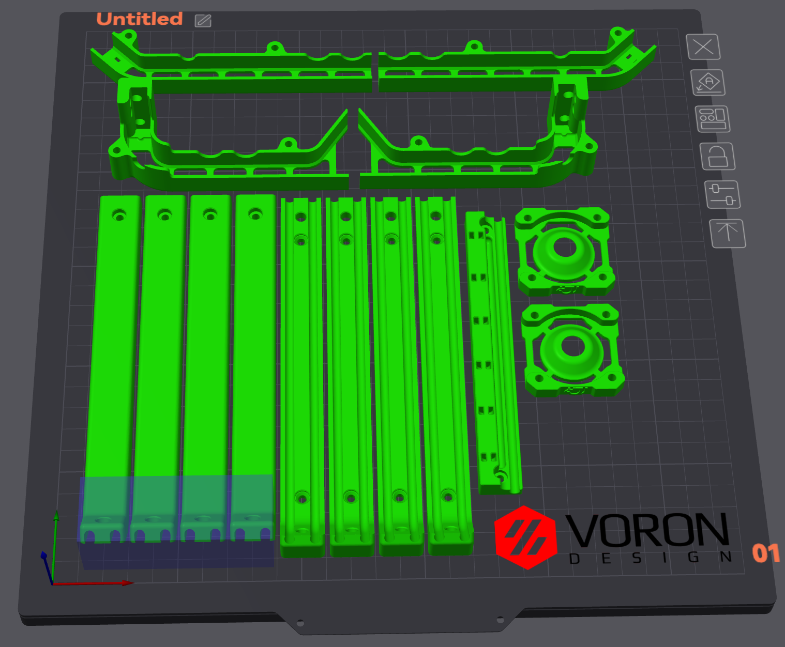
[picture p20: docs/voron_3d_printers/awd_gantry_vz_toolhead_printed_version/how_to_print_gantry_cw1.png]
How to print the mammoth-3D cable routing parts


!!! tip
    Only add support on the one side of the 4x Pipe / Cable Holders

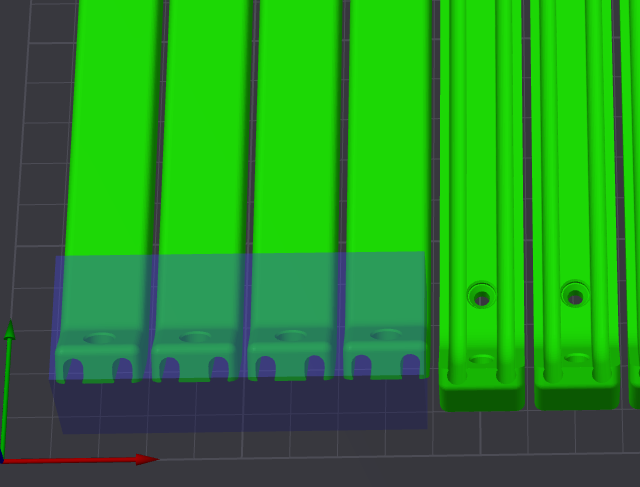
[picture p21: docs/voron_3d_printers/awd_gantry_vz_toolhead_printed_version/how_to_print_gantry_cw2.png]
How to print the mammoth-3D Pipe / Cable Holders


## **Cable routing and water cooling Parts to print**
| **Qty** | **Name** | **Layer hight** | **Wall loops/Min. Wall Thickness** | **Top/Bottom shell layers** |**Infill** | **Material** | **Accent Color** |
|---|---|---|---|---|---|---|-|
| 2x | [Nema17 Stand-off](https://www.printables.com/model/1100104-voron-24-mammoth-3d-awd-gantry-v173-cable-manageme/files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)  | 0.2mm | **4**/1.6mm | 5 | 42% | ABS/ASA/PA-CF | :material-check: Yes |
| 1x | [Motor Endstop Cover Right](https://www.printables.com/model/1100104-voron-24-mammoth-3d-awd-gantry-v173-cable-manageme/files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)  | 0.2mm | **4**/1.6mm | 5 | 42% | ABS/ASA | :material-close: No |
| 1x | [Motor Endstop Cover Left](https://www.printables.com/model/1100104-voron-24-mammoth-3d-awd-gantry-v173-cable-manageme/files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)  | 0.2mm | **4**/1.6mm | 5 | 42% | ABS/ASA/PA-CF | :material-close: No |
| 1x | [Motor Cable Routing Right Voron24_300](https://www.printables.com/model/1100104-voron-24-mammoth-3d-awd-gantry-v173-cable-manageme/files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)  | 0.2mm | **4**/1.6mm | 5 | 42% | ABS/ASA | :material-check: Yes |
| 1x | [Motor Cable Routing Left Voron24_300](https://www.printables.com/model/1100104-voron-24-mammoth-3d-awd-gantry-v173-cable-manageme/files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)  | 0.2mm | **4**/1.6mm | 5 | 42% | ABS/ASA | :material-check: Yes |
| 4x | [Y Axis Pipe Cable Holder Top Voron24_300](https://www.printables.com/model/1100104-voron-24-mammoth-3d-awd-gantry-v173-cable-manageme/files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)  | 0.2mm | **4**/1.6mm | 5 | 42% | ABS/ASA/PA-CF | :material-close: No |
| 4x | [Y Axis Pipe Cable Holder Bottom Voron24_300](https://www.printables.com/model/1100104-voron-24-mammoth-3d-awd-gantry-v173-cable-manageme/files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)  | 0.2mm | **4**/1.6mm | 5 | 42% | ABS/ASA/PA-CF | :material-close: No |
| 1x | [Back Pipe Cable Managment Voron24_300](https://www.printables.com/model/1100104-voron-24-mammoth-3d-awd-gantry-v173-cable-manageme/files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)  | 0.2mm | **4**/1.6mm | 5 | 42% | ABS/ASA/PA-CF | :material-close: No |
| 1x | [Motor Cable Routing Right Voron24_350](https://www.printables.com/model/1100104-voron-24-mammoth-3d-awd-gantry-v173-cable-manageme/files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)  | 0.2mm | **4**/1.6mm | 5 | 42% | ABS/ASA | :material-check: Yes |
| 1x | [Motor Cable Routing Left Voron24_350](https://www.printables.com/model/1100104-voron-24-mammoth-3d-awd-gantry-v173-cable-manageme/files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)  | 0.2mm | **4**/1.6mm | 5 | 42% | ABS/ASA | :material-check: Yes |
| 4x | [Y Axis Pipe Cable Holder Top Voron24_350](https://www.printables.com/model/1100104-voron-24-mammoth-3d-awd-gantry-v173-cable-manageme/files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)  | 0.2mm | **4**/1.6mm | 5 | 42% | ABS/ASA/PA-CF | :material-close: No |
| 4x | [Y Axis Pipe Cable Holder Bottom Voron24_350](https://www.printables.com/model/1100104-voron-24-mammoth-3d-awd-gantry-v173-cable-manageme/files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)  | 0.2mm | **4**/1.6mm | 5 | 42% | ABS/ASA/PA-CF | :material-close: No |
| 1x | [Back Pipe Cable Managment Voron24_350](https://www.printables.com/model/1100104-voron-24-mammoth-3d-awd-gantry-v173-cable-manageme/files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)  | 0.2mm | **4**/1.6mm | 5 | 42% | ABS/ASA/PA-CF | :material-close: No |

## **How to print KNOMI V2 Mount**

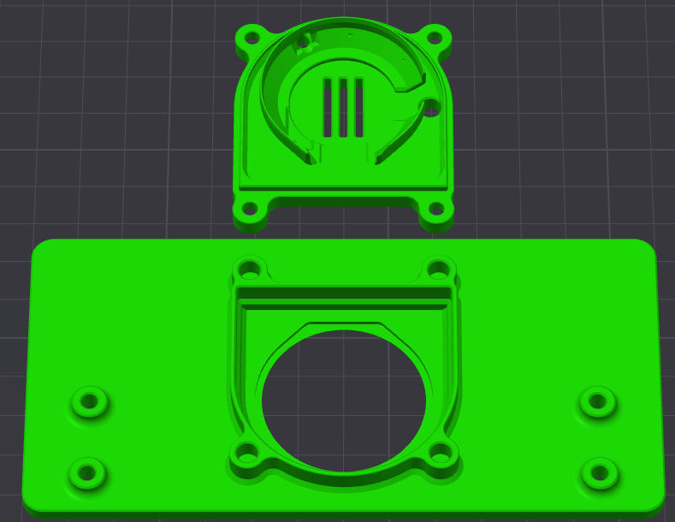
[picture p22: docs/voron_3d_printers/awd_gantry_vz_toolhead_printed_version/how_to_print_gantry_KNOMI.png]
How to print the mammoth-3D AWD Gantry parts


## **KNOMI V2 mount parts to print**
| **Qty** | **Name** | **Layer hight** | **Wall loops/Min. Wall Thickness** | **Top/Bottom shell layers** |**Infill** | **Material** | **Accent Color** |
|---|---|---|---|---|---|---|-|
| 1x | [Knomi v2 Front](https://www.printables.com/model/1124028-voron-24-mammoth-3d-awd-gantry-v173-knomi-v2-mount/files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)  | 0.2mm | **4**/1.6mm | 5 | 42% | ABS/ASA | :material-close: No |
| 1x | [Knomi v2 Back](https://www.printables.com/model/1124028-voron-24-mammoth-3d-awd-gantry-v173-knomi-v2-mount/files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)  | 0.2mm | **4**/1.6mm | 5 | 42% | ABS/ASA/PA-CF | :material-close: No |

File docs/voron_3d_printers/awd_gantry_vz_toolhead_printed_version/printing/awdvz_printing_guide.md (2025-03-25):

# **Printing Guide**

## **Version 1.00 / 04. March 2025**

## **Primary Color**

Example: `mammoth-3d X1 Top v173.step`
These files have no prefix in their filename so are safe to print in your primary color.

## **Accent Color**

Example: `[A] mammoth-3d U Arm x2.3mf`
These files are prefixed with `[A]` and are intended to be printed in your accent color.

## **Quantity Required**

Example: `[A] mammoth-3d Bearing Clamp x4.3mf`
If any file ends with `x#`, that is telling you the quantity of that part required to build the Gantry.

## **Required Size**

Example: `mammoth-3d Pipe Cable Holder Bottom Voron24_350.3mf`
If any file ends with `printername_#`, that is telling you to only print the size required for your printer size.

## **Support and Drilling Out Holes**

No need for that (99% whahahaha) :octicons-heart-fill-24:{ .heart } But maybe you need to cleanup your 3D printed parts.

!!! note "Layer Height and Line Width"
    Some parts have supporting layers to allow unsupported features to be printed successfully. These supports are designed to work at a layer height of **0.2mm**, so they may not be sliced correctly if your layer height is not **0.2mm**.

## **How to print AWD gantry parts**

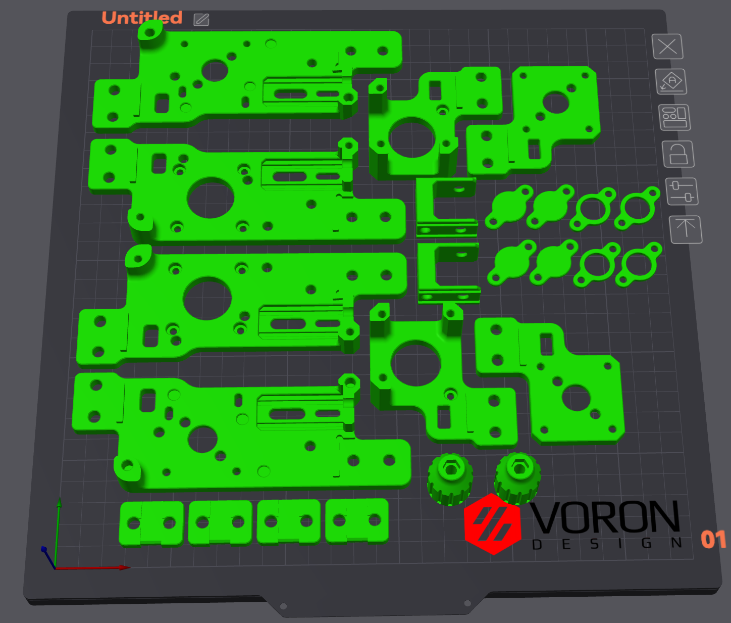
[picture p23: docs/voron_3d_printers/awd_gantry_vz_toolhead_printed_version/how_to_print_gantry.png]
How to print the mammoth-3D AWD Gantry parts


## **Parts to print**
| **Qty** | **Name** | **Layer hight** | **Wall loops/Min. Wall Thickness** | **Top/Bottom shell layers** |**Infill** | **Material** | **Accent Color** |
|---|---|---|---|---|---|---|-|
| 1x | [X Motor Mount Top](https://www.printables.com/model/1096743-voron-24-mammoth-3d-awd-gantry-v173-x-and-y-motor/files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) | 0.2mm | **5**/2mm | 5 | 85% |ABS/ASA/PA-CF | :material-close: No |
| 1x | [X Motor Mount Bottom](https://www.printables.com/model/1096743-voron-24-mammoth-3d-awd-gantry-v173-x-and-y-motor/files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) | 0.2mm | **5**/2mm | 5 | 85% | ABS/ASA/PA-CF | :material-close: No |
| 1x | [Y Motor Mount Top](https://www.printables.com/model/1096743-voron-24-mammoth-3d-awd-gantry-v173-x-and-y-motor/files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)  | 0.2mm | **5**/2mm | 5 | 85% | ABS/ASA/PA-CF | :material-close: No |
| 1x | [Y Motor Mount Bottom](https://www.printables.com/model/1096743-voron-24-mammoth-3d-awd-gantry-v173-x-and-y-motor/files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)  | 0.2mm | **5**/2mm | 5 | 85% | ABS/ASA/PA-CF | :material-close: No |
| 1x | [X1 Motor Mount Top](https://www.printables.com/model/1097920-voron-24-mammoth-3d-awd-gantry-v173-x1-and-y1-moto/files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)  | 0.2mm | **5**/2mm | 5 | 65% | ABS/ASA | :material-close: No |
| 1x | [X1 Motor Mount Bottom](https://www.printables.com/model/1097920-voron-24-mammoth-3d-awd-gantry-v173-x1-and-y1-moto/files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)  | 0.2mm | **5**/2mm | 5 | 65% | ABS/ASA | :material-close: No |
| 1x | [Y1 Motor Mount Top](https://www.printables.com/model/1097920-voron-24-mammoth-3d-awd-gantry-v173-x1-and-y1-moto/files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)  | 0.2mm | **5**/2mm | 5 | 65% | ABS/ASA | :material-close: No |
| 1x | [Y1 Motor Mount Bottom](https://www.printables.com/model/1097920-voron-24-mammoth-3d-awd-gantry-v173-x1-and-y1-moto/files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)  | 0.2mm | **5**/2mm | 5 | 65% | ABS/ASA | :material-close: No |
| 2x | [Tension Knob](https://www.printables.com/model/1097920-voron-24-mammoth-3d-awd-gantry-v173-x1-and-y1-moto/files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)  | 0.2mm | **4**/1.6mm | 5 | 42% | ABS/ASA | :material-check: Yes |
| 2x | [U ARM](https://www.printables.com/model/1097920-voron-24-mammoth-3d-awd-gantry-v173-x1-and-y1-moto/files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)  | 0.2mm | **4**/1.6mm | 5 | 65% | ABS/ASA | :material-check: Yes |
| 4x | [Voron Belt Clamps](https://www.printables.com/model/1097920-voron-24-mammoth-3d-awd-gantry-v173-x1-and-y1-moto/files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)  | 0.2mm | **4**/1.6mm | 5 | 42% | ABS/ASA | :material-check: Yes |
| 4x | [Bearing Clamp](https://www.printables.com/model/1097920-voron-24-mammoth-3d-awd-gantry-v173-x1-and-y1-moto/files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)  | 0.2mm | **4**/1.6mm | 5 | 42% | ABS/ASA | :material-check: Yes |

!!! tip
    Not everyone uses long shaft motors, and there is no need to change your motors to use the gantry.
    If you are using standard motors in your build, you might consider using bearing covers to close the bearing hole.

## **Bearing Cover**
| **Qty** | **Name** | **Layer hight** | **Wall loops/Min. Wall Thickness** | **Top/Bottom shell layers** |**Infill** | **Material** | **Accent Color** |
|---|---|---|---|---|---|---|-|
| 2x | [Bearing Cover](https://www.printables.com/model/1097920-voron-24-mammoth-3d-awd-gantry-v173-x1-and-y1-moto/files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)  | 0.2mm | **4**/1.6mm | 5 | 42% | ABS/ASA | :material-check: Yes |
| 1x | [Bearing Clamp Logo Right](https://www.printables.com/model/1096743-voron-24-mammoth-3d-awd-gantry-v173-x-and-y-motor/files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)  | 0.2mm | **4**/1.6mm | 5 | 42% | ABS/ASA | :material-check: Yes |
| 1x | [Bearing Clamp Logo Left](https://www.printables.com/model/1096743-voron-24-mammoth-3d-awd-gantry-v173-x-and-y-motor/files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)  | 0.2mm | **4**/1.6mm | 5 | 42% | ABS/ASA | :material-check: Yes |

!!! tip
    Not everyone is interested in an AWD gantry system, so we also offer a 2WD option. The front idler mounts replace the need for the X/Y motor mounts.

### **How to print 2WD gantry parts**

How to print the mammoth-3D 2WD Gantry parts

## **2WD Parts to print**
| **Qty** | **Name** | **Layer hight** | **Wall loops/Min. Wall Thickness** | **Top/Bottom shell layers** |**Infill** | **Material** | **Accent Color** |
|---|---|---|---|---|---|---|-|
| 1x | [2WD X Top](https://www.printables.com/model/1113851-voron-24-mammoth-3d-2wd-gantry-v173-x-and-y-idler/files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)  | 0.2mm | **4**/1.6mm | 5 | 42% | ABS/ASA/PA-CF | :material-close: No |
| 1x | [2WD X Bottom](https://www.printables.com/model/1113851-voron-24-mammoth-3d-2wd-gantry-v173-x-and-y-idler/files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)  | 0.2mm | **4**/1.6mm | 5 | 42% | ABS/ASA/PA-CF | :material-close: No |
| 1x | [2WD Y Top](https://www.printables.com/model/1113851-voron-24-mammoth-3d-2wd-gantry-v173-x-and-y-idler/files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)  | 0.2mm | **4**/1.6mm | 5 | 42% | ABS/ASA/PA-CF | :material-close: No |
| 1x | [2WD Y Bottom](https://www.printables.com/model/1113851-voron-24-mammoth-3d-2wd-gantry-v173-x-and-y-idler/files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)  | 0.2mm | **4**/1.6mm | 5 | 42% | ABS/ASA/PA-CF | :material-close: No |

### **How to print motor cable routing and water cooling**

How to print the mammoth-3D cable routing parts

!!! tip
    Only add support on the one side of the 4x Pipe / Cable Holders

How to print the mammoth-3D Pipe / Cable Holders

## **Cable routing and water cooling Parts to print**
| **Qty** | **Name** | **Layer hight** | **Wall loops/Min. Wall Thickness** | **Top/Bottom shell layers** |**Infill** | **Material** | **Accent Color** |
|---|---|---|---|---|---|---|-|
| 2x | [Nema17 Stand-off](https://www.printables.com/model/1100104-voron-24-mammoth-3d-awd-gantry-v173-cable-manageme/files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)  | 0.2mm | **4**/1.6mm | 5 | 42% | ABS/ASA/PA-CF | :material-check: Yes |
| 1x | [Motor Endstop Cover Right](https://www.printables.com/model/1100104-voron-24-mammoth-3d-awd-gantry-v173-cable-manageme/files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)  | 0.2mm | **4**/1.6mm | 5 | 42% | ABS/ASA | :material-close: No |
| 1x | [Motor Endstop Cover Left](https://www.printables.com/model/1100104-voron-24-mammoth-3d-awd-gantry-v173-cable-manageme/files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)  | 0.2mm | **4**/1.6mm | 5 | 42% | ABS/ASA/PA-CF | :material-close: No |
| 1x | [Motor Cable Routing Right Voron24_300](https://www.printables.com/model/1100104-voron-24-mammoth-3d-awd-gantry-v173-cable-manageme/files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)  | 0.2mm | **4**/1.6mm | 5 | 42% | ABS/ASA | :material-check: Yes |
| 1x | [Motor Cable Routing Left Voron24_300](https://www.printables.com/model/1100104-voron-24-mammoth-3d-awd-gantry-v173-cable-manageme/files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)  | 0.2mm | **4**/1.6mm | 5 | 42% | ABS/ASA | :material-check: Yes |
| 4x | [Y Axis Pipe Cable Holder Top Voron24_300](https://www.printables.com/model/1100104-voron-24-mammoth-3d-awd-gantry-v173-cable-manageme/files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)  | 0.2mm | **4**/1.6mm | 5 | 42% | ABS/ASA/PA-CF | :material-close: No |
| 4x | [Y Axis Pipe Cable Holder Bottom Voron24_300](https://www.printables.com/model/1100104-voron-24-mammoth-3d-awd-gantry-v173-cable-manageme/files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)  | 0.2mm | **4**/1.6mm | 5 | 42% | ABS/ASA/PA-CF | :material-close: No |
| 1x | [Back Pipe Cable Managment Voron24_300](https://www.printables.com/model/1100104-voron-24-mammoth-3d-awd-gantry-v173-cable-manageme/files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)  | 0.2mm | **4**/1.6mm | 5 | 42% | ABS/ASA/PA-CF | :material-close: No |
| 1x | [Motor Cable Routing Right Voron24_350](https://www.printables.com/model/1100104-voron-24-mammoth-3d-awd-gantry-v173-cable-manageme/files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)  | 0.2mm | **4**/1.6mm | 5 | 42% | ABS/ASA | :material-check: Yes |
| 1x | [Motor Cable Routing Left Voron24_350](https://www.printables.com/model/1100104-voron-24-mammoth-3d-awd-gantry-v173-cable-manageme/files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)  | 0.2mm | **4**/1.6mm | 5 | 42% | ABS/ASA | :material-check: Yes |
| 4x | [Y Axis Pipe Cable Holder Top Voron24_350](https://www.printables.com/model/1100104-voron-24-mammoth-3d-awd-gantry-v173-cable-manageme/files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)  | 0.2mm | **4**/1.6mm | 5 | 42% | ABS/ASA/PA-CF | :material-close: No |
| 4x | [Y Axis Pipe Cable Holder Bottom Voron24_350](https://www.printables.com/model/1100104-voron-24-mammoth-3d-awd-gantry-v173-cable-manageme/files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)  | 0.2mm | **4**/1.6mm | 5 | 42% | ABS/ASA/PA-CF | :material-close: No |
| 1x | [Back Pipe Cable Managment Voron24_350](https://www.printables.com/model/1100104-voron-24-mammoth-3d-awd-gantry-v173-cable-manageme/files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)  | 0.2mm | **4**/1.6mm | 5 | 42% | ABS/ASA/PA-CF | :material-close: No |

## **How to print KNOMI V2 Mount**

How to print the mammoth-3D AWD Gantry parts

## **KNOMI V2 mount parts to print**
| **Qty** | **Name** | **Layer hight** | **Wall loops/Min. Wall Thickness** | **Top/Bottom shell layers** |**Infill** | **Material** | **Accent Color** |
|---|---|---|---|---|---|---|-|
| 1x | [Knomi v2 Front](https://www.printables.com/model/1124028-voron-24-mammoth-3d-awd-gantry-v173-knomi-v2-mount/files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)  | 0.2mm | **4**/1.6mm | 5 | 42% | ABS/ASA | :material-close: No |
| 1x | [Knomi v2 Back](https://www.printables.com/model/1124028-voron-24-mammoth-3d-awd-gantry-v173-knomi-v2-mount/files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)  | 0.2mm | **4**/1.6mm | 5 | 42% | ABS/ASA/PA-CF | :material-close: No |

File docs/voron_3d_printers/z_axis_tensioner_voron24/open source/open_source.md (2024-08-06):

# **Open Source** 

<script src="https://cdn.logwork.com/widget/countdown.js"></script>
<a href="https://logwork.com/countdown-timer" class="countdown-timer" data-timezone="Europe/Zurich" data-textcolor="#050505" data-date="2025-01-24 23:59" data-digitscolor="#fa0a0a" data-unitscolor="#050505">Days remaining till the files becomes open source.</a>

### **Supporting Innovation with mammoth-3D. Read more [Link](/how_your_support_helps/supporting_innovation/)**

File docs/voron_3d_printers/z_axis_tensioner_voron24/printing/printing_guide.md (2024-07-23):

# **Printing Guide**

## **Primary Color**

Example: `mammoth Voron Z Idler Main Body Left.stl`
These files have no prefix in their filename so are safe to print in your primary color.

## **Accent Color**

Example: `[A] mammoth-3D Voron2.4 Z Idler_V1.3 A x2.stl`
These files are prefixed with `[A]` and are intended to be printed in your accent color.

## **Quantity Required**

Example: `mammoth-3D Voron2.4 Z Idler_V1.3 Tensioner x2.stl`
If any file ends with `x#`, that is telling you the quantity of that part required to build the Z-Axis Belt Tensioner.

## **Support and Drilling Out Holes**

No need for that :octicons-heart-fill-24:{ .heart } 

!!! note "Layer Height and Line Width"
    Some parts have supporting layers to allow unsupported features to be printed successfully. These supports are designed to work at a layer height of **0.2mm**, so they may not be sliced correctly if your layer height is not **0.2mm**.

## **How to print**

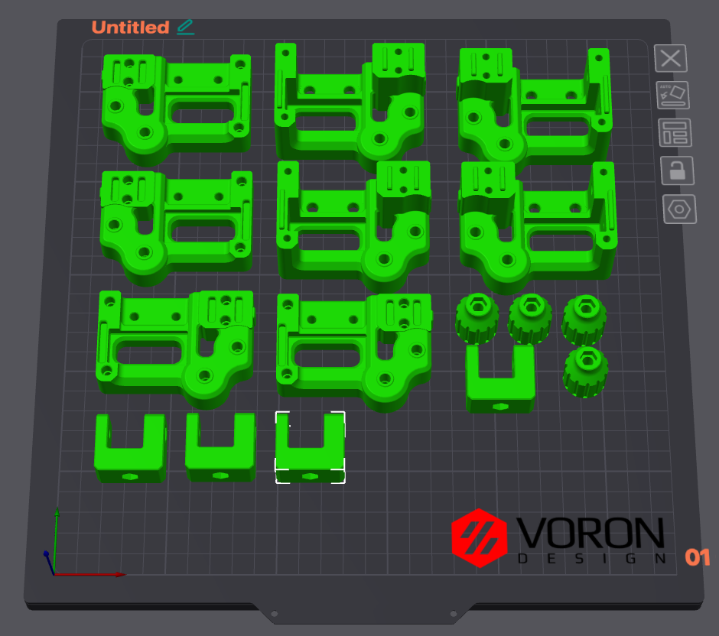
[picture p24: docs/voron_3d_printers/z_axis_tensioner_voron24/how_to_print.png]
How to print Tool-free Z-Axis Belt Tensioner


## **Parts to print**
| **Qty** | **Name** | **Layer hight** | **Wall loops/Min. Wall Thickness** | **Top/Bottom shell layers** |**Infill** | **Material** | **Accent Color** |
|---|---|---|---|---|---|---|-|
| 2x | [Belt Tensioner Mainbody Right  ](https://www.printables.com/model/918365-tool-free-z-axis-belt-tensioner-for-voron-24) | 0.2mm | **4**/1.6mm | 5 | 42% |ABS/ASA/PA-CF | :material-close: No |
| 2x | [Belt Tensioner Coverbody Right ](https://www.printables.com/model/918365-tool-free-z-axis-belt-tensioner-for-voron-24) | 0.2mm | **4**/1.6mm | 5 | 42% | ABS/ASA/PA-CF | :material-close: No |
| 2x | [Belt Tensioner Mainbody Left ](https://www.printables.com/model/918365-tool-free-z-axis-belt-tensioner-for-voron-24)  | 0.2mm | **4**/1.6mm | 5 | 42% | ABS/ASA/PA-CF | :material-close: No |
| 2x | [Belt Tensioner Coverbody Left  ](https://www.printables.com/model/918365-tool-free-z-axis-belt-tensioner-for-voron-24)  | 0.2mm | **4**/1.6mm | 5 | 42% | ABS/ASA/PA-CF | :material-close: No |
| 4x | [U Body ](https://www.printables.com/model/918365-tool-free-z-axis-belt-tensioner-for-voron-24)  | 0.2mm | **6**/2mm | 5 | 60% | ABS/ASA | :material-check: Yes |
| 4x | [Tension Knob ](https://www.printables.com/model/918365-tool-free-z-axis-belt-tensioner-for-voron-24)  | 0.2mm | **4**/1.6mm | 5 | 42% | ABS/ASA | :material-check: Yes |

!!! tip
    The "Tensioner" can be printed only once and you don't need to keep it on the printer. You will only need them to tension your belts. But can be removed afterwards.

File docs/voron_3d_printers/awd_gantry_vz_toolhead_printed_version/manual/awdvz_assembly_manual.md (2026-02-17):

# **AWD Gantry with VZBOT Toolhead for Voron 2.4 3D Printers Preassembly Manual:**

## **Version 1.00 / 04. March 2025**

## **U Arm / Tensioner Arm**

<iframe width="560" height="315" src="https://www.youtube.com/embed/RYmKq4i0vH8?si=29SUPhCDgSQn3vLp" title="YouTube video player" frameborder="0" allow="accelerometer; autoplay; clipboard-write; encrypted-media; gyroscope; picture-in-picture; web-share" referrerpolicy="strict-origin-when-cross-origin" allowfullscreen></iframe>

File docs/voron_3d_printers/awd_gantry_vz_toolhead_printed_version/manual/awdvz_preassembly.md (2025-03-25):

# **AWD Gantry with VZBOT Toolhead for Voron 2.4 3D Printers Preassembly Manual:**

## **Version 1.00 / 04. March 2025**

## **U Arm / Tensioner Arm**

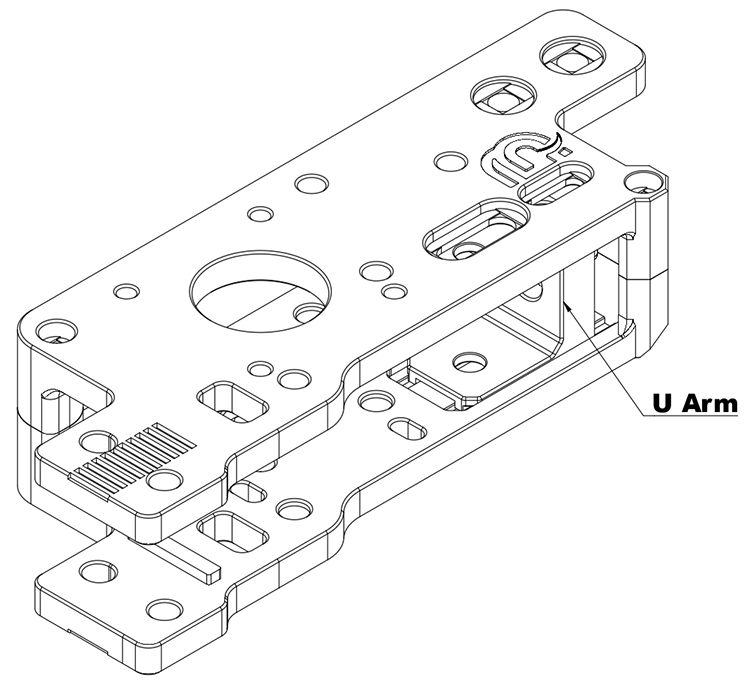
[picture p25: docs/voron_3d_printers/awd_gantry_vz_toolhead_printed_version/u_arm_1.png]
U Arm Check


- Check that the U Arm/Tensioner Arm moves freely from left to right. If you feel resistance, inspect the 3D-printed parts and remove any unwanted filament blobs. This step **is crucial** before assembling the gantry. Once you're satisfied with the movement, repeat the process for the second one.

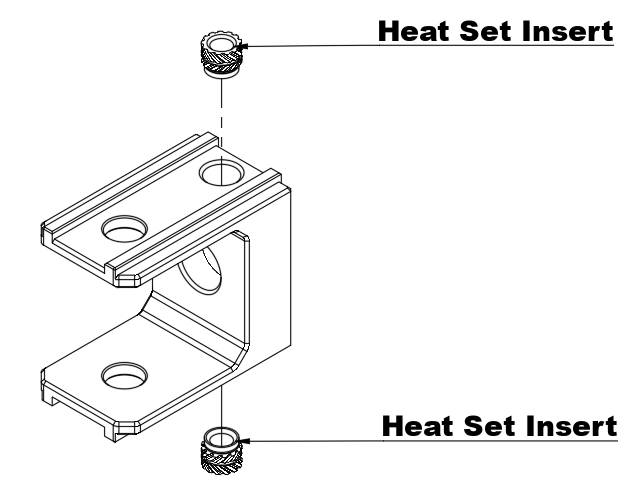
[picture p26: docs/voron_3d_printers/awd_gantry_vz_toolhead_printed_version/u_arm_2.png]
U Arm heat set inserts


- Install two heat set inserts and repeat the process for the second one.

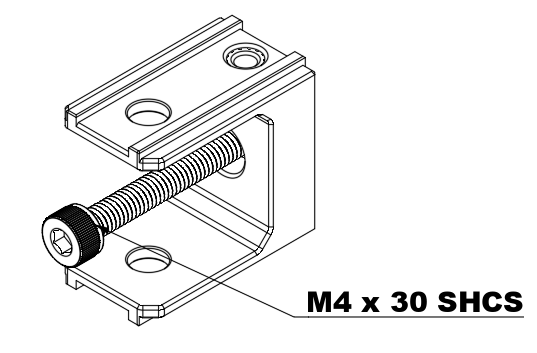
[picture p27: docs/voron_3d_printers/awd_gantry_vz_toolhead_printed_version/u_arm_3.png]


- **Don`t over Tighten** The M4 bolt threads directly into plastic, repeat the process for the second one.

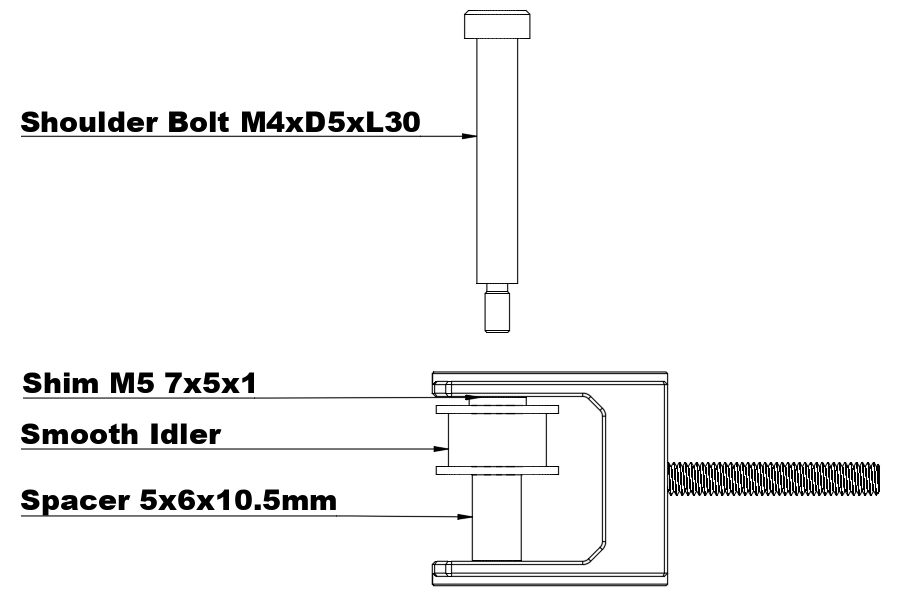
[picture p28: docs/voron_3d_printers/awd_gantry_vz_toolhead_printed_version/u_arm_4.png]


- In this step, the M4xD5xL30 Shoulder Bolt is used as an **assembly aid**. It helps align components and will be removed in a later step.
- Using the assembly aid, install one 7x5x1mm shim, a smooth idler and a 5x6x10.5mm spacer.
- Repeat the process for the second one.

!!! tip
    There is no top or bottom side in this step, so both tensioners should look the same.
    **Check that both smooth idlers move freely.**

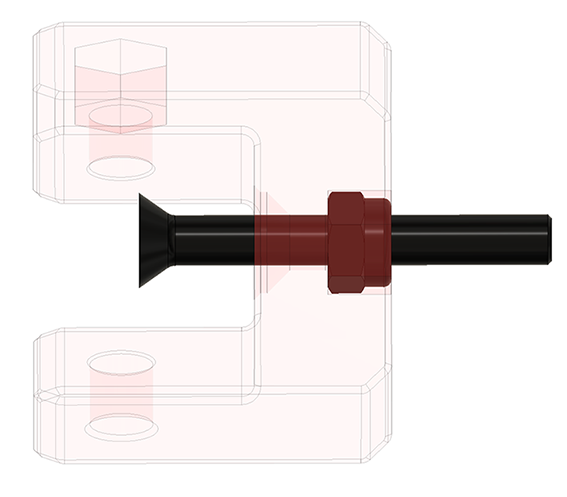
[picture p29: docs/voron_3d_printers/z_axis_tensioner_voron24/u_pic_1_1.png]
Belt Tensioner Preassembly


!!! warning
    If the M4 Flat Head Screw is screwd in to deep, it will not fit if you assemble the Tensioner. We will screw it in all the way in a later stage.

!!! tip
    Repeat the same step for all 4x U prices.

---

Take 4x threaded inserts and install them into the Cover Body (short body).

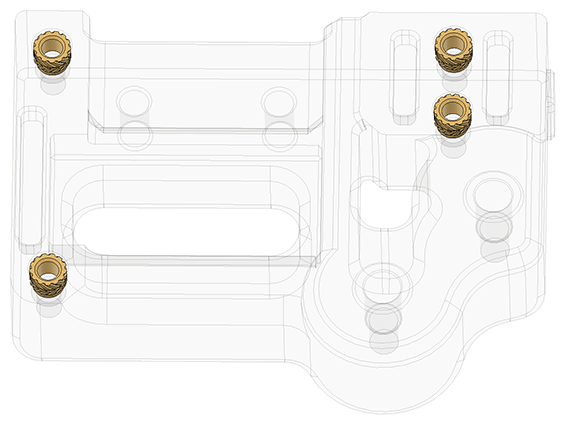
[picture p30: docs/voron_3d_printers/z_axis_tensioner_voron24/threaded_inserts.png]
Threaded inserts


!!! tip
    Repeat the same step for all 4x Cover Bodys.

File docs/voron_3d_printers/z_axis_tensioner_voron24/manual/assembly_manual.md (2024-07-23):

# **Tool-free Z-Axis Belt Tensioner for Voron 2.4 3D Printers Assembly Manual:**

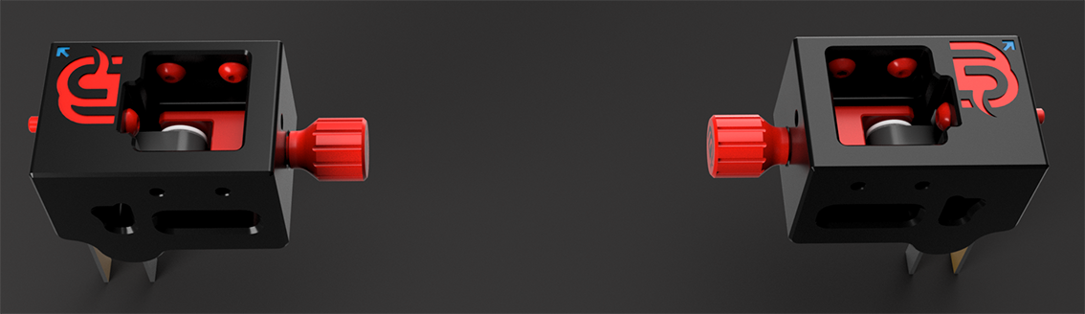
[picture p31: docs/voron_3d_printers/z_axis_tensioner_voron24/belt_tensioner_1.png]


Take one of the Main Bodys and insert the U Pic assembly. The fat side fits into the Main Body.

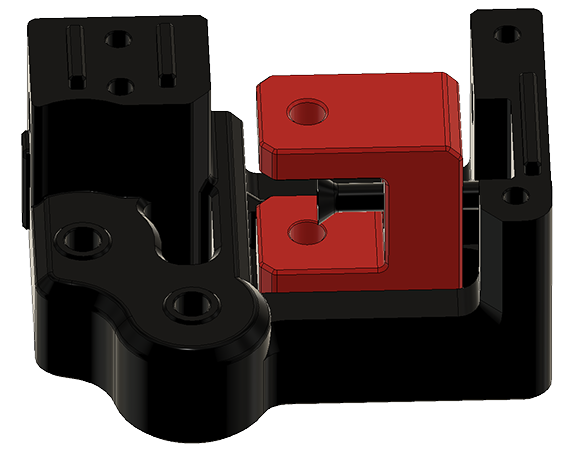
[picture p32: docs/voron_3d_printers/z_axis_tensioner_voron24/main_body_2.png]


Now screw in the Flat Head Screw all the way and add 1x M4 washer 9x4x1mm and 1x M4 lock nut on the outside of the Main Body.

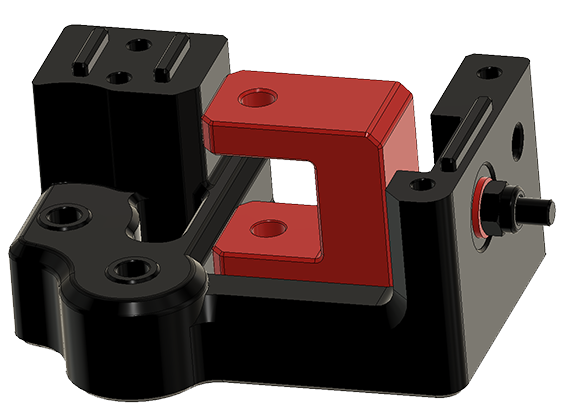
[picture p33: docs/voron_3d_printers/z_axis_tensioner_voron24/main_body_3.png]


!!! tip
    Test if the Tensioner can move easy forwards and backwords. Now is the time to check and fix any problems. Later this step will not be so easy to fix or change.

---

Insert a M4 lock nut into the U Pic, take one 25mm sholder bolt and insert it into the U Pic. In the inside you should have a M5 5x7x1mm Shim - Mellow Pulleys 14/11 20 Tooth Wheel Bore 5mm GT2 - M5 5x7x1mm Shim. Screw the sholder bolt into the lock nut and check that the pulley can move freely.
!!! Warning
    Do not over tighten the sholder bolt! Or the Pully will not be able to turn freely.

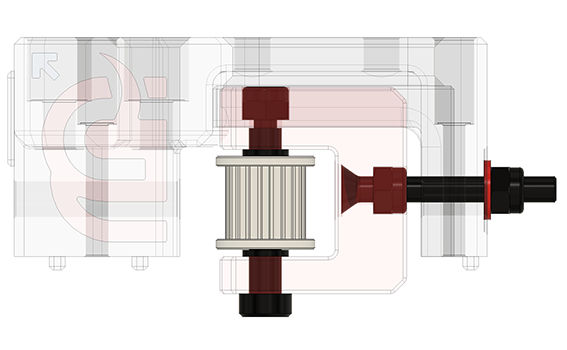
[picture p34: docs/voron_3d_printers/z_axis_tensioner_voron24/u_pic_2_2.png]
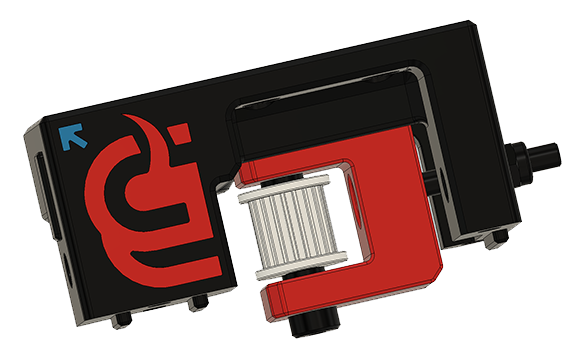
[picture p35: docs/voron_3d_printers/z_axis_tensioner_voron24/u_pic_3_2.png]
 

---

Insert 2x 30mm Sholder bolt into the Main Body.
!!! Warning
    Yes, it should be hard to push the sholder bolts into the 5mm hole! Don't make the holes bigger, as we dont want any play on the sholder bolts or pulleys.

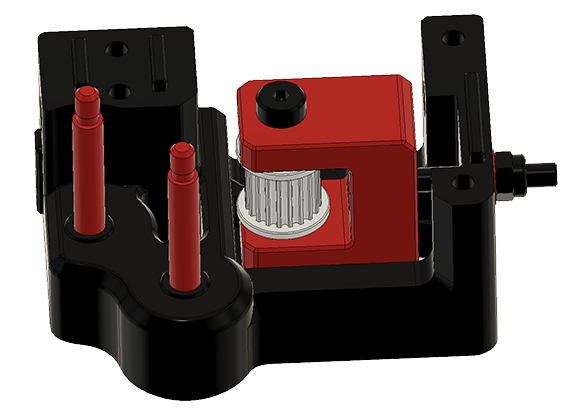
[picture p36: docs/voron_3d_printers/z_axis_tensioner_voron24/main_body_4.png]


Install 2x M5 5x7x1mm shims, one on each sholder bolt.

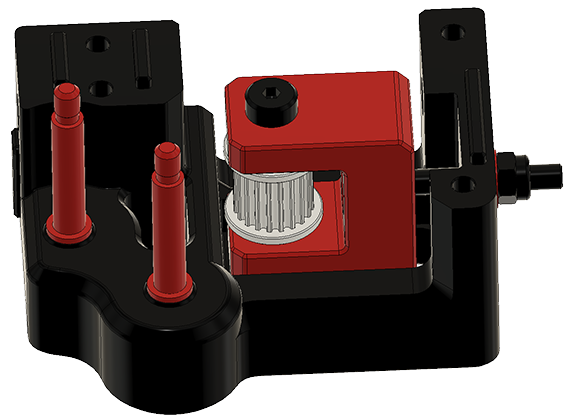
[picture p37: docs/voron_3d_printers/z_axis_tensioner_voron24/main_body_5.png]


Install 1x Mellow Pulley 14/11 20 Tooth Wheel Bore 5mm GT2 on the outside and 1x Mellow Pulley 14/11 Smooth Wheel Bore 5mm GT2 in the inside.

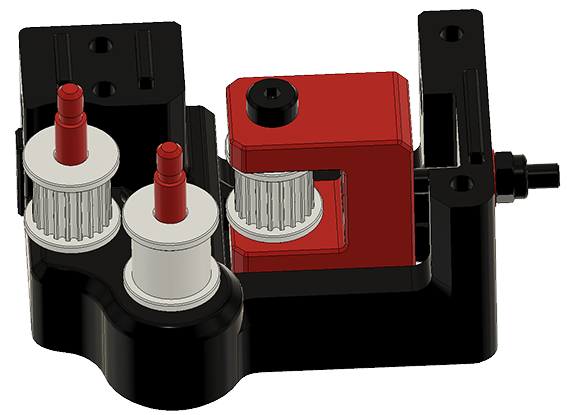
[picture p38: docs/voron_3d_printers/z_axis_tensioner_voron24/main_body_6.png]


Install 2x M5 5x7x1mm shims, one on each sholder bolt.

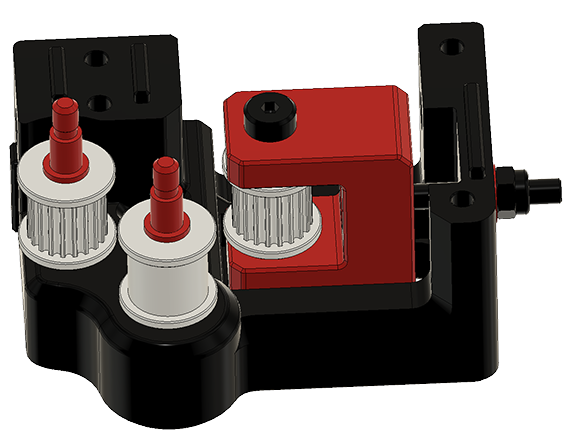
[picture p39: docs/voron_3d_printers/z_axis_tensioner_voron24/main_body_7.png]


Take the matching Cover Body and screw the sholder bolts into the Cover Body till they start threading into the 3D printed part. Dont screw it in all the way!!

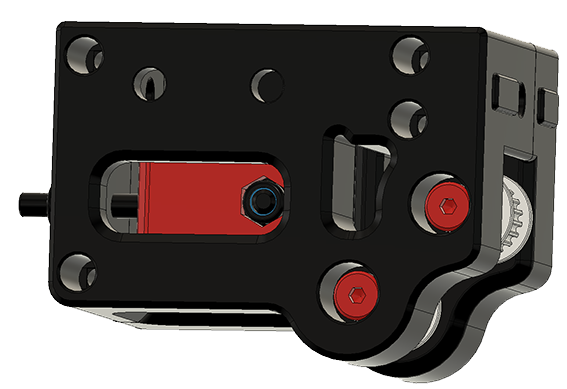
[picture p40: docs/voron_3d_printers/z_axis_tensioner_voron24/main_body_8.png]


Take 4x M3 SHCS 25mm screws and install them into the Mail Body.

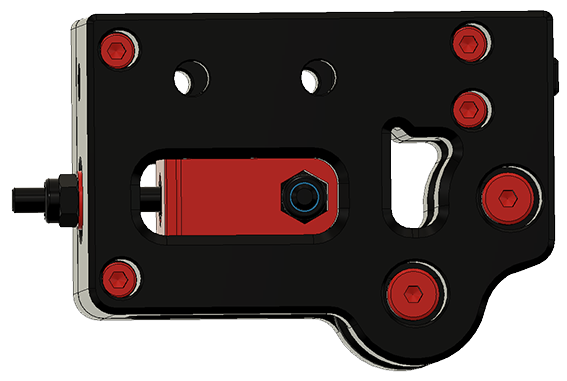
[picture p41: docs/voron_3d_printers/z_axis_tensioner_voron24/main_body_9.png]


Now screw in the sholder bolts.

!!! Tip
    Don't over tighten them!! And check that the pulleys can move freely.

Repeat the same steps for all 4x Tensioner Bodys.

## **Get your Printer ready for the Z-Axis Belt Tensioner:**

- Move you gantry all the way down or secure it so that it will not drop when removing the Z belts!
- Once the gantry is secure, remove your stock Z Idlers and belts. You will need new belts, as the once installed are not long enough.

## **Install the Tool-free Z-Axis Belt Tensioner**

Install 3x Drop-in T-nut, M5 in each top corner. One in the Y-Axis and two in the front/back profile.
!!! Tip
    If you have Drop-in T-nut installed you can reuse them and just move and add one more per corner. If you are using M5 Hammer Head T-Nuts. Please change them for M5 T-nut.

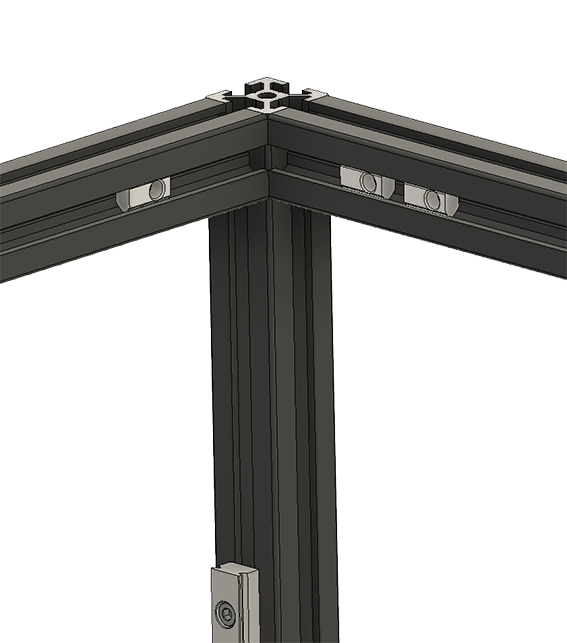
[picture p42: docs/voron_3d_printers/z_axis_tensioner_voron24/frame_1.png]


Check that you find the arrow on the tensioner body. In the image its in **blue**. The arrow has to be facing the corner when installing the belt tensiner.

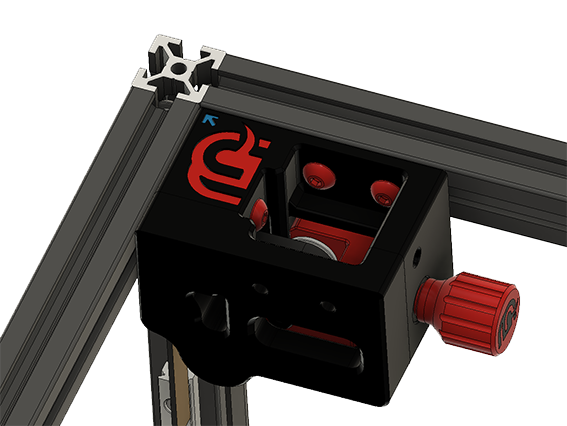
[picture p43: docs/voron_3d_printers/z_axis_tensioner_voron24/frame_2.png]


Take one of the M5x30 BHCS screws and secure it in the screw possition under the mammoth-3D Logo.

!!! Tip
    When installing the M5x30 BHCS screw, press the Tension Body as good as possible into the corner.

Take two of the M5x10 BHCS screw and install them into the provided holes.

Do the same steps for all 4 Tension Bodys.

---

Install your new 9mm GT2 belts. Make sure that the Belt Tensioner is loose and all the way in the Tension Body.

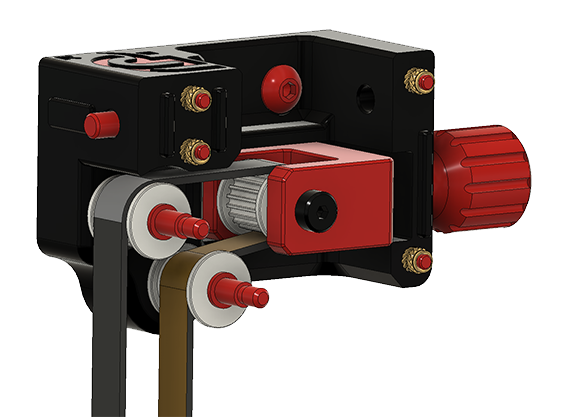
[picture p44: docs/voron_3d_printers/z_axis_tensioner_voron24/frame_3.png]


You can tension your belt by turning the tension-knob.

!!! Warning
    It is very easy to over tension your belts with the mammoth-3D belt tensioner. Remeber to test the tension of your belts as you turn the knob.

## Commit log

2024-07-23 Tool-free Z-Axis Belt Tensioner for Voron 2.4
    [belt_tensioner_coverbody_left_Ver.1.00 x2.3mf, belt_tensioner_coverbody_right_Ver.1.00 x2.3mf, belt_tensioner_mainbody_left_Ver.1.00 x2.3mf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]
2024-12-03 mammoth-3D AWD Gantry BOM
2025-03-25 AWD Gantry Documentation Update
2025-03-27 Idler Setup
2025-04-03 Belt Tension Calculator
2026-02-20 Elegoo Orange Storm Giga - Bill of material
2026-03-04 Tip: X-axis needs to be modified
2026-04-27 behemoth Gantry BOM
2026-04-30 Updated behemoth BOM
2026-04-30 BOM Updates
